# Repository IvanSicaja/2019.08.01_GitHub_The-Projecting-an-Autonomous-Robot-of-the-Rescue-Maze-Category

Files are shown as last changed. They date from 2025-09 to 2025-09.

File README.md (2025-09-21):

🧾 🎯 **Project Title:** **THE PROJECTING AN AUTONOMOUS ROBOT OF THE RESCUE MAZE CATEGORY**  
📅 **Project Timeline:** **August 2019 – October 2021**  
🎥 YouTube Demo: [Link: https://youtu.be/3sTD7d_HzC4](https://youtu.be/3sTD7d_HzC4)  
📦 GitHub Source Code: <https://github.com/IvanSicaja/2019.08.01_GitHub_The-Projecting-an-Autonomous-Robot-of-the-Rescue-Maze-Category>  
\----------------------------------------------------------------------------------------------------------------

🏷️ My Personal Profiles: ⬇︎  
🎥 Video Portfolio: To be added  
📦 GitHub Profile: <https://github.com/IvanSicaja>  
🔗 LinkedIn: <https://www.linkedin.com/in/ivan-si%C4%8Daja-832682222>  
🎥 YouTube: <https://www.youtube.com/@ivan_sicaja>  
\----------------------------------------------------------------------------------------------------------------

### 📚🔍 Project description: ⬇︎⬇︎⬇︎

### 💡 App Purpose

To design a **rescue maze mobile robot** with autonomous **navigation, victim detection, and package delivery**, capable of operating in **unpredictable rescue environments** with robust AI-driven perception.

**Key Robot Capabilities:**

- **Autonomous character recognition (OCR)**
- **Autonomous color recognition**
- **Partially autonomous drive in the maze** (need a lot of testing and calibration for fully autonomous drive and labyrinth mapping)
- **Thermal victim recognition**
- **Package delivery**
- **Ability to master a climb of 25 degrees** (all-wheel drive, strong grip)
- **Independent axle maneuvering**
- **Remembering positions (encoders)**...

**🧠 How It Works**  
The project is very complex and demands knowledge in different areas (**3D modeling, 3D printing, advanced programming skills in different languages, researching ability, expert knowledge of every electrical component working principles, image processing, cause-and-effect analysis...**)  
The brains of the robot are **microcontroller Teensy 3.5** and **Raspberry Pi 4B**.

The robot is also equipped with:

- **2x optical camera**
- **2x thermal camera**
- **6x IR lidar sensor**
- **1x color sensor**... (more can be found at GitHub in my publication paper: _The projecting an autonomous robot of the rescue maze category.pdf_ -> Caption 4.3)

**Optical character recognition:**  
In this project, we trained a **Convolutional Neural Network (CNN)** on an image examples with the Python module **TensorFlow**. Images are converted into **.CSV file** because of speeder processing. The input image is filtered with different filters (**Grayscale, Gaussian Blur, Threshold, Binary, Dilatation**) in order to speed up image processing (replace three color channels with one channel, **RGB -> grayscale**). Reduce noises (the dust on the live video capturing). Getting smooth and sharp character edges is the most important characteristic for successful character recognition. The trained model accuracy is **77.54%** which is a target because we want to get high reliability and avoid CNN overfitting.

**Object detection:**  
Developed the custom script with the Python computer vision module **OpenCV** which filters the character that should be recognized from the other objects in the robot's surroundings. The script works on the principle of **character height and proportion**, together with the **dynamic noise filtering**.

**Maze mapping:**  
Maze mapping is done in my Python module **Turtle**. Every maze field is properly recognized by the robot's **distance and color sensors**. After all maze fields are mapped, they are sent to the backend and the shortest path is calculated by the artificial intelligence searching algorithms such as: _Breadth-First Search, Depth-First Search, A Algorithm_\*...

**Hardware choosing and connecting:**  
The entire process of choosing **hardware platforms, supported protocols, and hardware capabilities** is done. E.g. the **video camera** must have a corresponding **focal length** otherwise it will be useless, **framerate, resolution, additional light source**, **motors** should have expected speed, **distance sensors** should be precise and able to work in a maze, **robot brain** should be able to do high computation payload and support Python…

**Frame design and 3D printing:**  
Entire robot is **3D designed** with **Fusion 360 CAD/CAM** software and **3D printed** with the **Ultimaker 3+** 3D printer with corresponding **filament, density**, etc.

**Developing mechatronic code:**  
**Arduino** is used to control all **sensors and actuators** on the robot except the **camera** which is controlled by **Raspberry Pi 4B** computer.

### ⚠️ Note

Achieving fully **autonomous drive** and **labyrinth mapping** requires extensive testing and calibration.  
I would especially like to thank **Mirko Pezo** and **Stjepan Mikulic** for their exceptional contribution to the development of this project .

### 🔧 Tech Stack

**Python, Convolutional Neural Network (CNN), OpenCV – Computer Vision, Pandas, TensorFlow, Keras, scikit-learn, Git, Linux, Fusion 360, 3D design, 3D printing, Arduino, Raspberry Pi, Teensy, Visual Studio Code, Turtle (Python), AI Search Algorithms (BFS, DFS, A\*)**

---

### 📸 Project Snapshot

<p align="center">
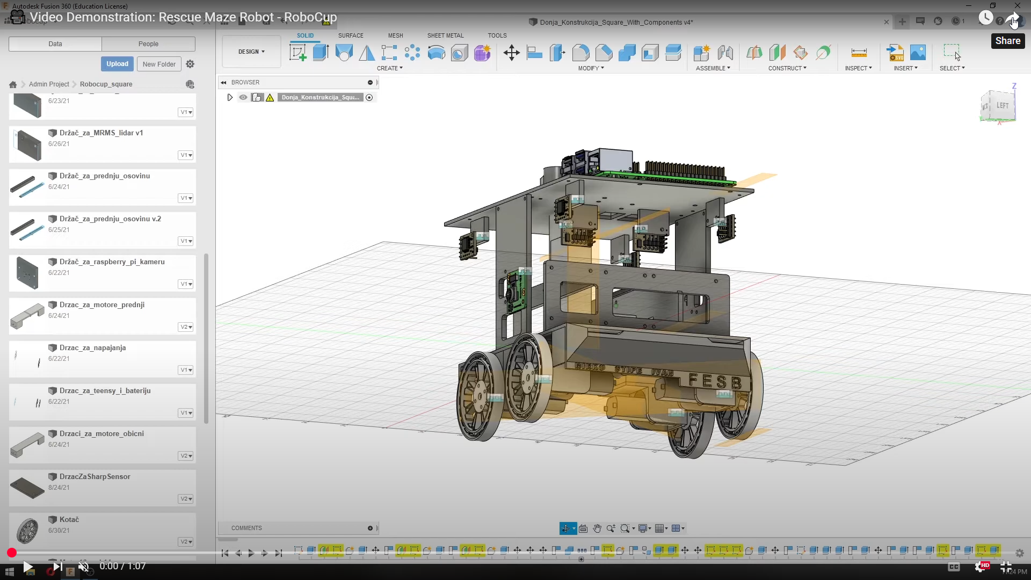
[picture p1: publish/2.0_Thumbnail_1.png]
Rescue Maze Robot Preview 1
  
</p>

<p align="center">
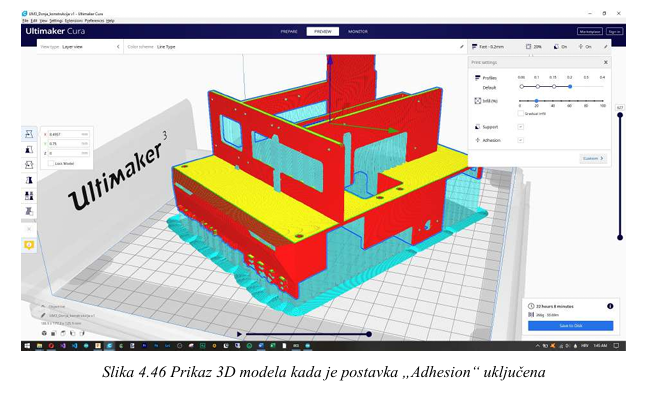
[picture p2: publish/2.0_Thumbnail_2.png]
Rescue Maze Robot Preview 2
  
</p>

<p align="center">
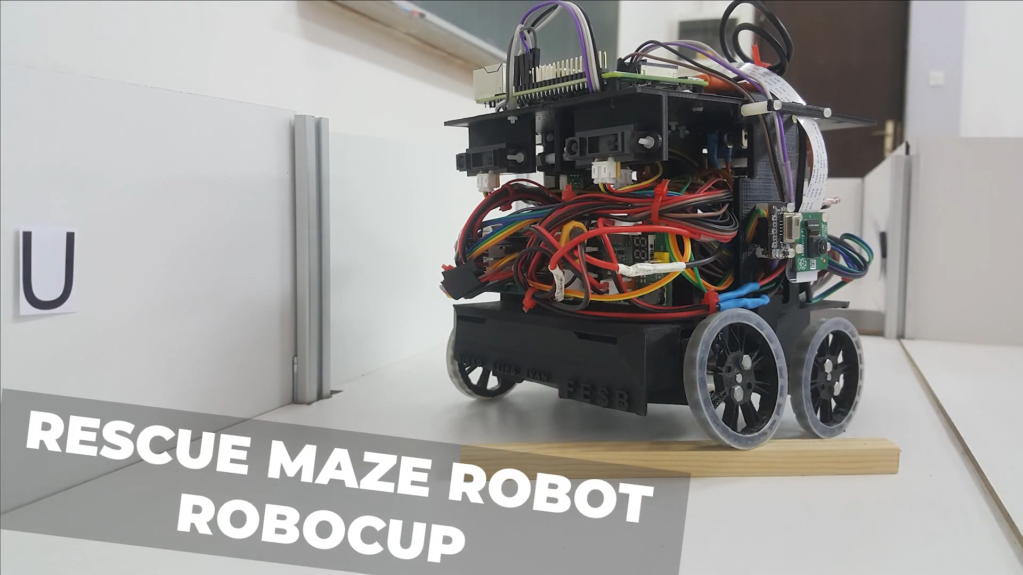
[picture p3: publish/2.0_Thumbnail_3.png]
Rescue Maze Robot Preview 3
  
</p>

<p align="center">
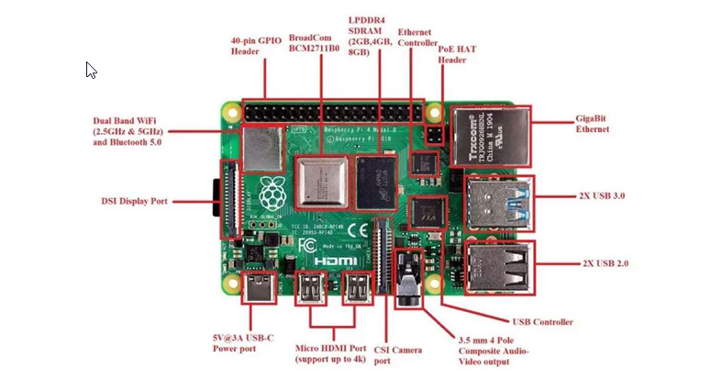
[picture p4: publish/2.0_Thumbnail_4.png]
Rescue Maze Robot Preview 4
  
</p>

<p align="center">
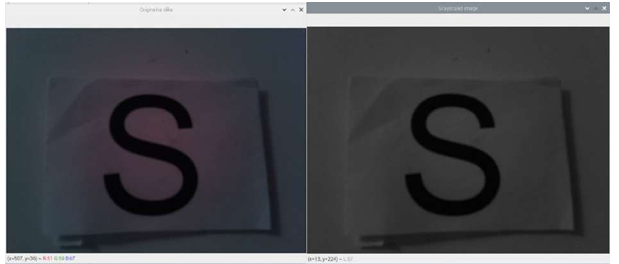
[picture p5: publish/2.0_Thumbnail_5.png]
Rescue Maze Robot Preview 5
  
</p>

<p align="center">
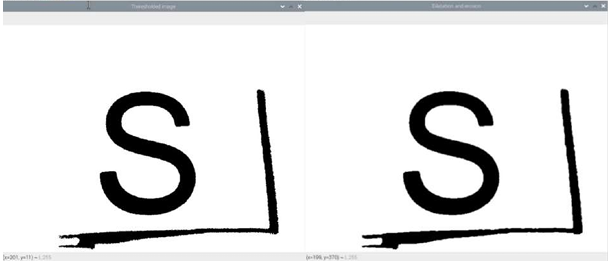
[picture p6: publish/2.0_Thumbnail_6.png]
Rescue Maze Robot Preview 6
  
</p>

<p align="center">
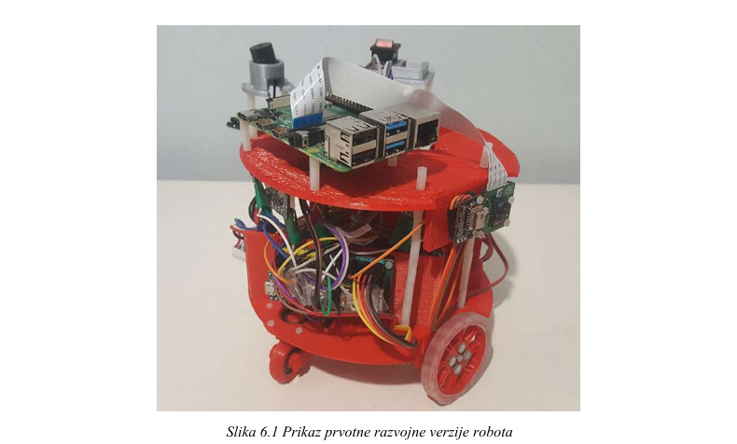
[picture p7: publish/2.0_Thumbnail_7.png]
Rescue Maze Robot Preview 7
  
</p>

---

### 🎥 Video Demonstration

<p align="center">
  <a href="https://youtu.be/3sTD7d_HzC4">
    Watch the demo
  </a>
</p>

---

### 📣 Hashtags Section

**\# #AutonomousRobotics #RescueMaze #RoboticsEngineering #AI #ComputerVision #OCR #ObjectDetection #PathPlanning #CNN #TensorFlow #OpenCV #EmbeddedSystems #RaspberryPi #Arduino #3DPrinting #Fusion360 #Mechatronics #AutonomousNavigation #MachineLearning**

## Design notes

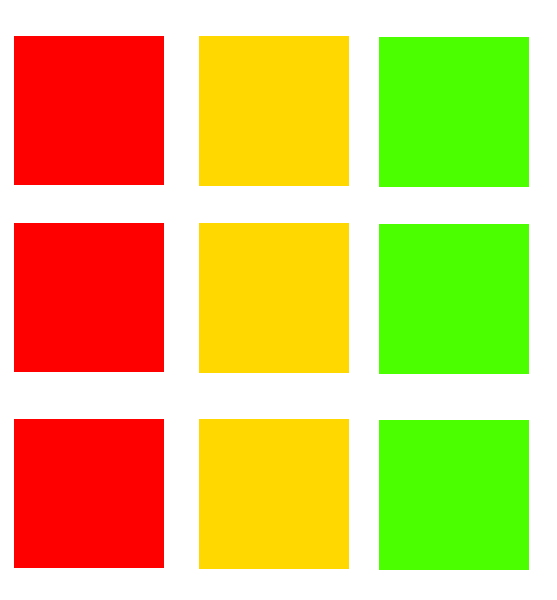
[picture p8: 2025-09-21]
docs/labyrinth/colorTarget.png

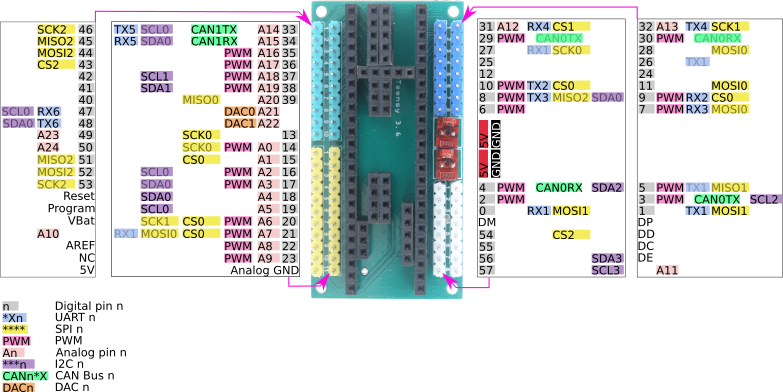
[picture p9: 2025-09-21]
docs/teensy/Teensy_3.6_Adapter_Pins.png

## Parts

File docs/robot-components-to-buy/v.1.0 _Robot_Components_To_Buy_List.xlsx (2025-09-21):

Number | Item | Quantity which we have | Item Price [$] | Price | Item Weight [g] | Weight [g] | Link
1 | Mikrokontrloer | 1 |  |  |  |  | https://www.pjrc.com/store/teensy36.html
2 | DC motors | 2 |  |  |  |  | https://www.pololu.com/product/3492
3 | DC motors Connectors | 2 |  |  |  |  | https://www.microline.hr/HTML.ashx?id=101
4 | Board for Tennesy | 1 |  |  |  |  | https://www.microline.hr/HTML.ashx?id=83
5 | Transformator and 8x8 display | 1 |  |  |  |  | https://www.microline.hr/HTML.ashx?id=40
6 | Motor Driver | 1 |  |  |  |  | https://www.microline.hr/HTML.ashx?id=37
7 | Themo Sensor | 1 |  |  |  |  | https://www.microline.hr/HTML.ashx?id=178
8 | Compas | 1 |  |  |  |  | https://www.microline.hr/HTML.ashx?id=140
9 | Position sensor | 1 |  |  |  |  | https://www.microline.hr/HTML.ashx?id=148
10 | PDB | 1
11 | Micro SD card
12 | Camrea | 1
13 | Raspberry PI 4 | 1 |  |  |  |  | https://www.raspberrypi.org/blog/raspberry-pi-4-on-sale-now-from-35/
14 | Raspberry PI 4 Camera V2 | 1 |  |  |  |  | https://www.raspberrypi.org/products/camera-module-v2/
15 | Line-traking sensor
16 | Battery | 1 |  |  |  |  | https://www.amazon.co.uk/Lipo-Battery-Turnigy-Nano-Tech-1300-mAh/dp/B018S936C8
17 | Frame
18 | Ampermeter
19 | Shaft Adpters | 4 |  |  |  |  | https://www.pololu.com/product/1081
Total

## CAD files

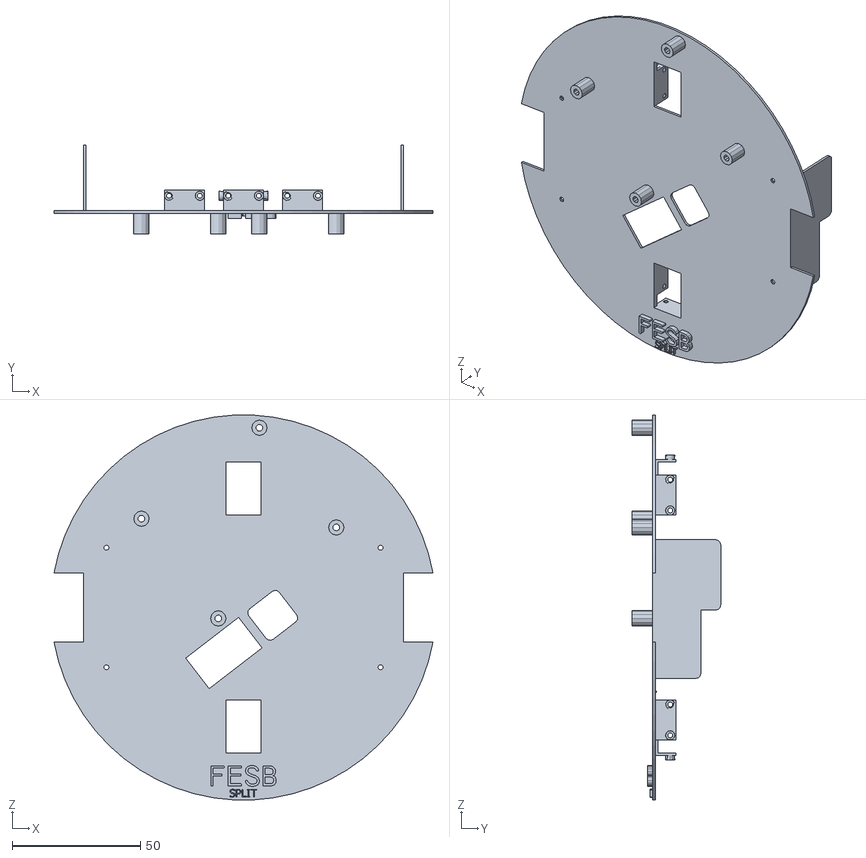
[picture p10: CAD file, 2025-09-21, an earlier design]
assets/3d-modeling/3D_Robot_Body_Parts_v.2.0/STL_files_for_print/Gornja_konstrukcija_s_držačima_assembly_converted_v.3.0.stl
147.5 x 34.5 x 149.8

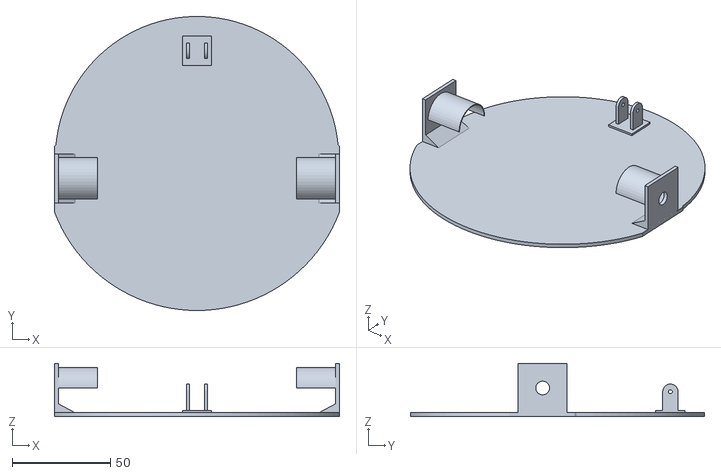
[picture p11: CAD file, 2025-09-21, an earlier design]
assets/3d-modeling/3D_Robot_Body_Parts_v.1.0/Konstrukcija/v.1.1 Konstrukcija.stl
145.0 x 149.5 x 27.0

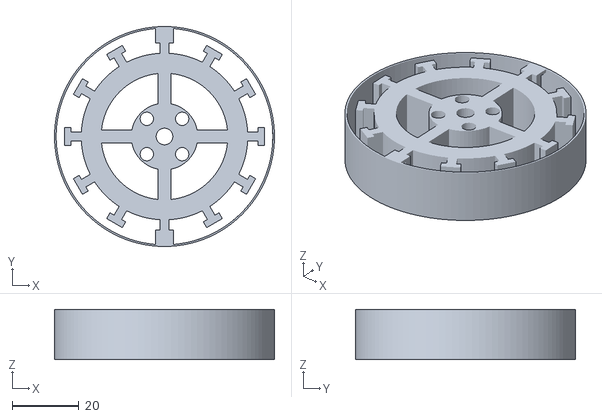
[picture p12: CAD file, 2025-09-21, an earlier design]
assets/3d-modeling/3D_Robot_Body_Parts_v.1.0/Kotači/3.0 kotač.stl
66.0 x 66.0 x 15.0

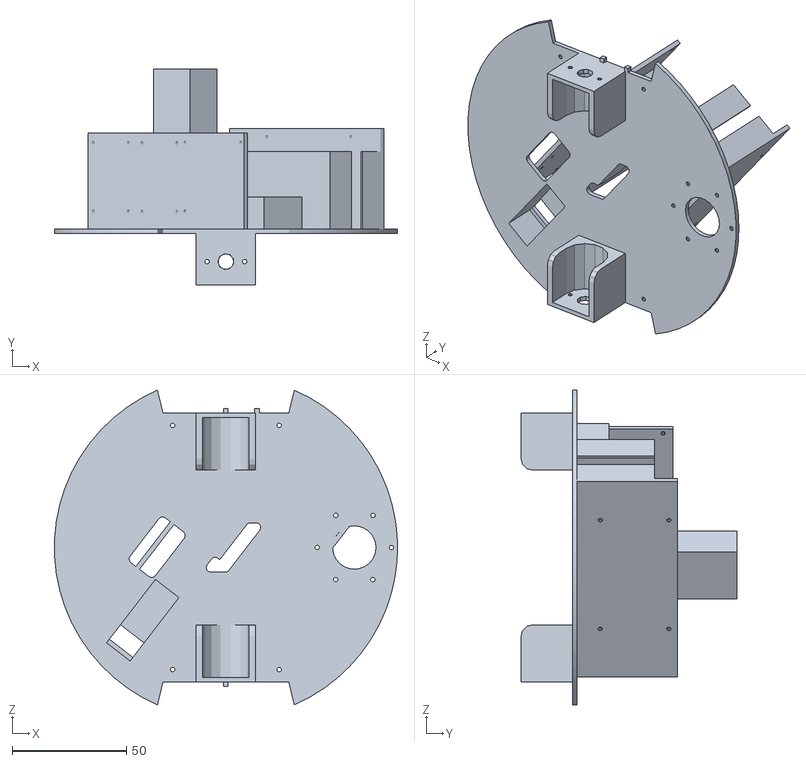
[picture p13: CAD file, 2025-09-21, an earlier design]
assets/3d-modeling/3D_Robot_Body_Parts_v.2.0/1_NewScratches/STL_Files/DonjaKonstrukcija_v.5.0..stl
149.9 x 94.4 x 137.6

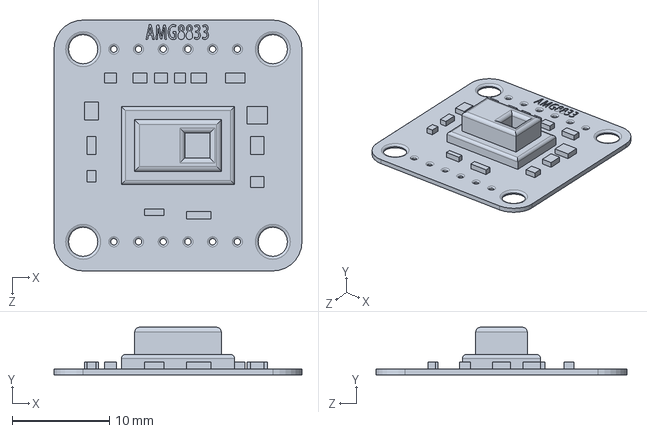
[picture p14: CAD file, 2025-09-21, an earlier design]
assets/3d-modeling/3D_Robot_Body_Parts_v.2.0/AdfruitThermalSensor/Camara AMG8833.SLDPRT
25.5 x 4.90 x 25.8 mm

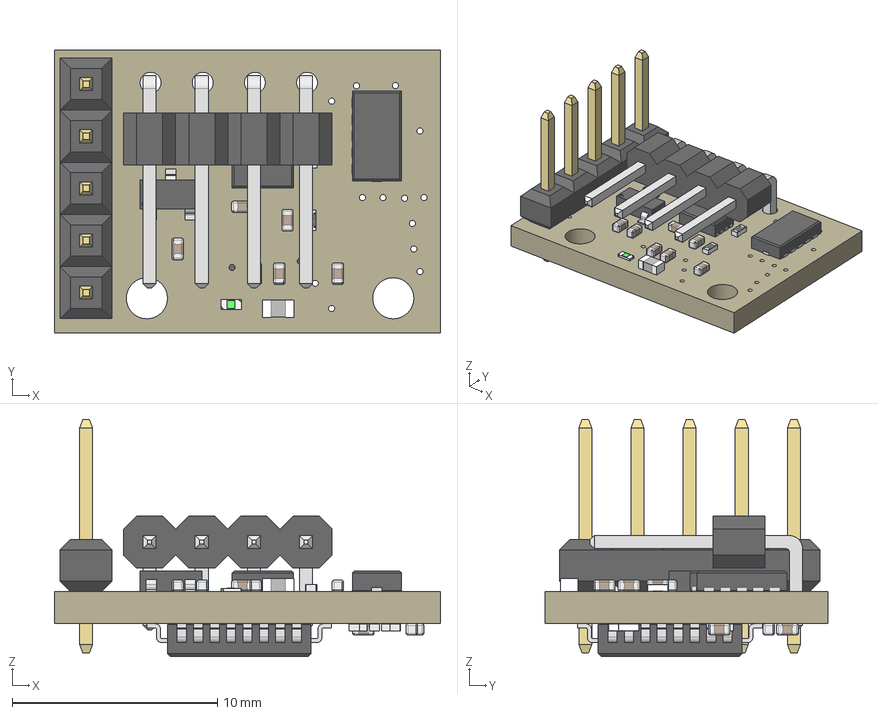
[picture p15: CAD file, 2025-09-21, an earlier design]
assets/3d-modeling/3D_Robot_Body_Parts_v.2.0/Lidar_MRMS/mrm-lid-an.step
18.8 x 13.8 x 11.6 mm
Board
4.7uF x 11
10 kOhm x 7
MICROCHIP_MCP1725T-ADJE/MC
STM_VL53LX
1X05
STM32F051K6T6
1X04_90DEG
SOT-23
FIDUCIAL1X2 x 2
CHIPLED_0402
1.5 kOhm

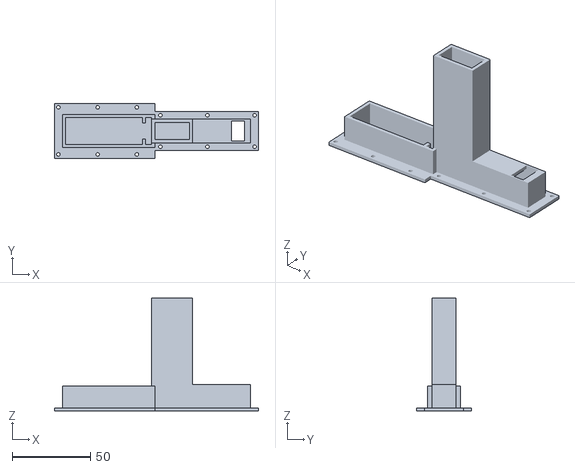
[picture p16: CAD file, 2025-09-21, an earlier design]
assets/3d-modeling/3D_Robot_Body_Parts_v.2.0/OldVersions/DropMechanism_v.1.1.stl
130.0 x 35.0 x 72.0

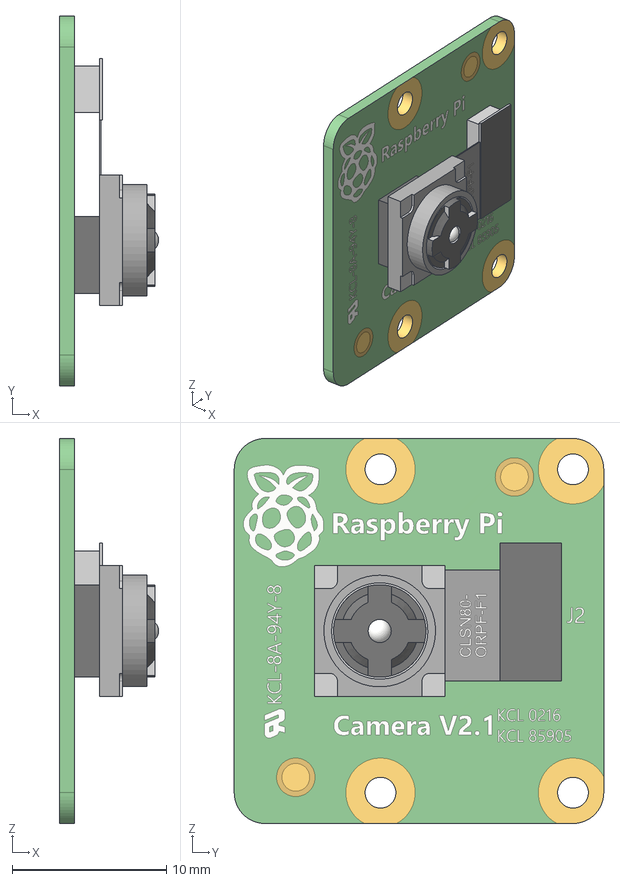
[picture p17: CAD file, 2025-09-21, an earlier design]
assets/3d-modeling/3D_Robot_Body_Parts_v.2.0/Raspberry Pi Camera Module 2.1/Cam V2.1 v1.step
6.45 x 24.0 x 25.0 mm

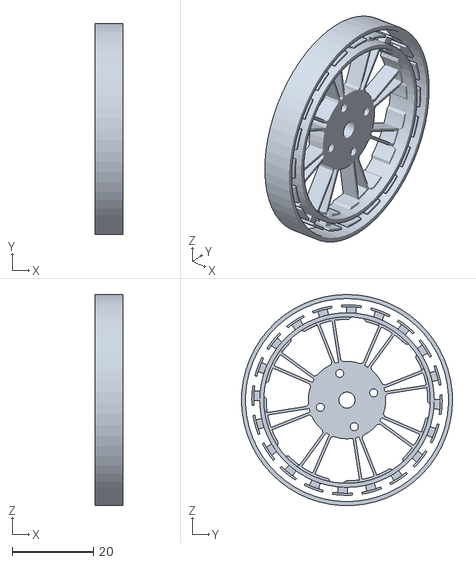
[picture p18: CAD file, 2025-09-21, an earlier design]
assets/3d-modeling/3D_Robot_Body_Parts_v.2.0/STL_files_for_print/Kotač_v.3.0..stl
7.00 x 52.0 x 52.0

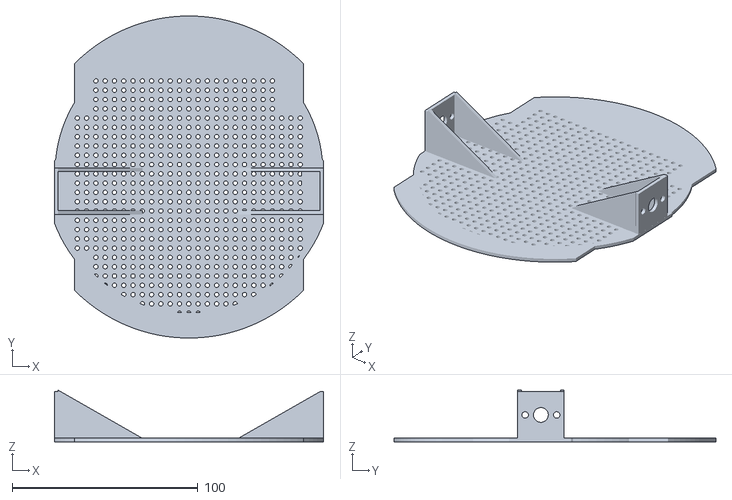
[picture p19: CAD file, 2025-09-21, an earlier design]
assets/3d-modeling/3D_Robot_Body_Parts_v.1.0/Konstrukcija/2.0 konstrukcija .stl
145.0 x 173.3 x 27.9

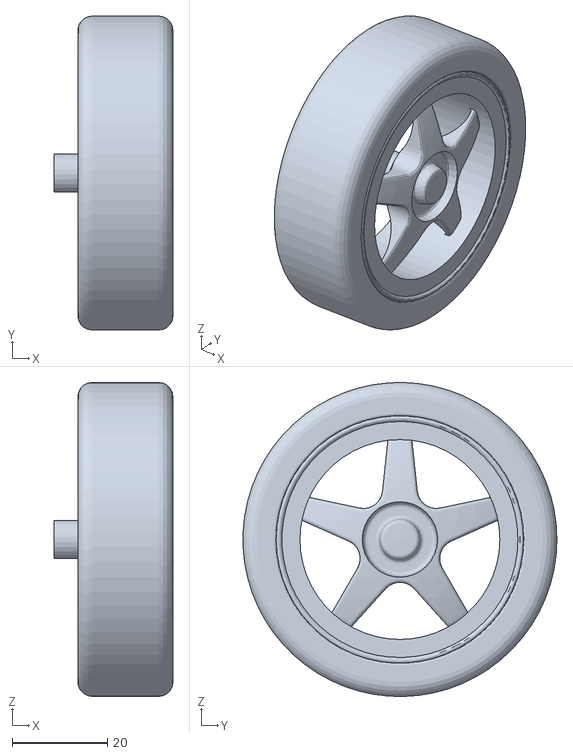
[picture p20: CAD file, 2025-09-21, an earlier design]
assets/3d-modeling/3D_Robot_Body_Parts_v.1.0/Kotači/v1.0 Kotač.obj
25.0 x 66.0 x 66.0

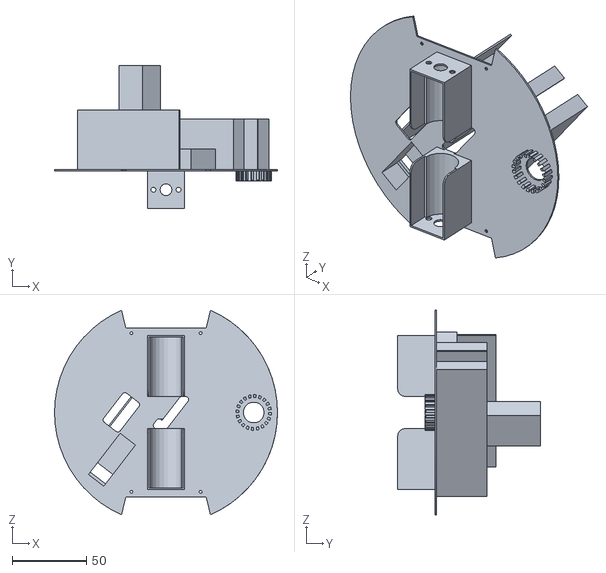
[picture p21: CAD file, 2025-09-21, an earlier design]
assets/3d-modeling/3D_Robot_Body_Parts_v.2.0/STL_files_for_print/Donja_konstrinkcija_s_drop_mehanizmom_v.2.stl
150.0 x 96.0 x 137.6

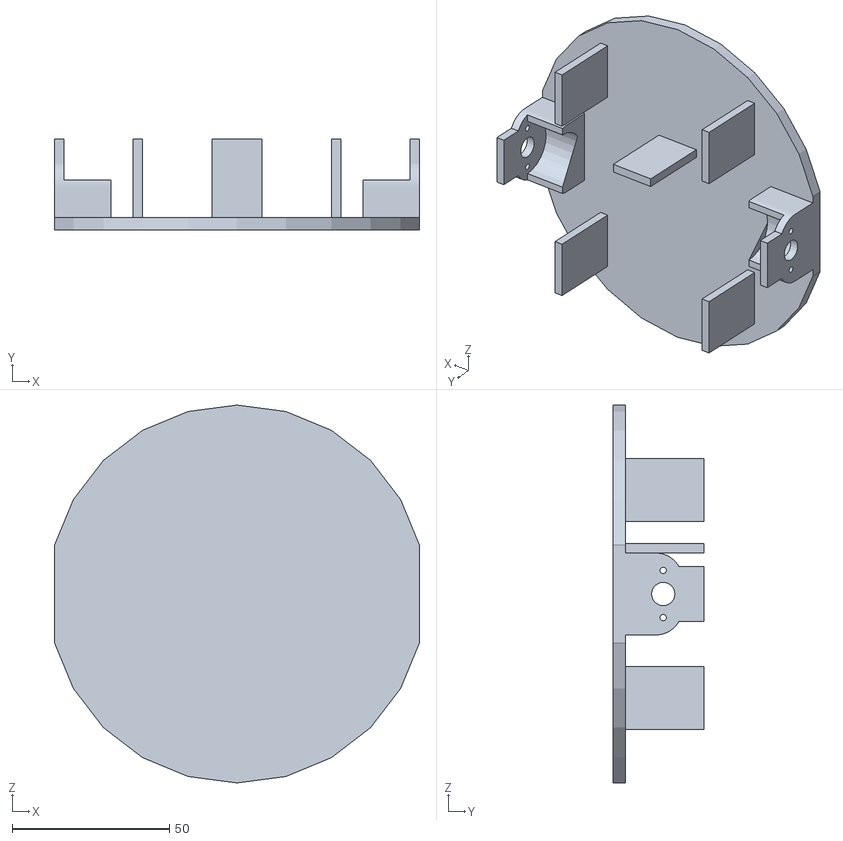
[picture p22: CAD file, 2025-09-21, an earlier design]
assets/3d-modeling/3D_Robot_Body_Parts_v.1.0/Konstrukcija/v.1.0 Konstrukcija.obj
115.9 x 29.0 x 120.0

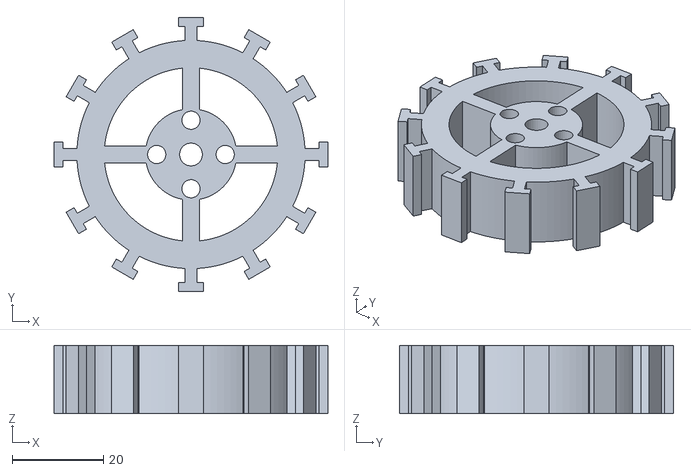
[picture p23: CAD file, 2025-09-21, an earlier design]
assets/3d-modeling/3D_Robot_Body_Parts_v.1.0/Kotači/v2.0 Kotač.stl
60.0 x 60.0 x 15.0

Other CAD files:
assets/3d-modeling/3D_Robot_Body_Parts_v.1.0/Konstrukcija/v.1.2 Konstrukcija.stl
assets/3d-modeling/3D_Robot_Body_Parts_v.1.0/Kotači/2.0 kotač s pomoći za ispunu s ljepilom.stl
assets/3d-modeling/3D_Robot_Body_Parts_v.2.0/STL_files_for_print/Paketici_za_izbacivanje_v.1.0.stl
assets/3d-modeling/3D_Robot_Body_Parts_v.2.0/STL_files_for_print/PrednjiKotač_635z_lezaj_v.2.0.stl
assets/3d-modeling/3D_Robot_Body_Parts_v.2.0/1_NewScratches/DodatniDržačZaLežaj_v.3.0.ipt
assets/3d-modeling/3D_Robot_Body_Parts_v.2.0/1_NewScratches/DonjaKonstrukcija_v.5.0.iam
assets/3d-modeling/3D_Robot_Body_Parts_v.2.0/1_NewScratches/DonjaKonstrukcija_v.5.0.ipt
assets/3d-modeling/3D_Robot_Body_Parts_v.2.0/1_NewScratches/DropMechanism_v.2.0.ipt
assets/3d-modeling/3D_Robot_Body_Parts_v.2.0/1_NewScratches/DrzacZaMotor_v.3.0.ipt
assets/3d-modeling/3D_Robot_Body_Parts_v.2.0/1_NewScratches/DrzacZaPrednjiKotač_v.1.0.ipt
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

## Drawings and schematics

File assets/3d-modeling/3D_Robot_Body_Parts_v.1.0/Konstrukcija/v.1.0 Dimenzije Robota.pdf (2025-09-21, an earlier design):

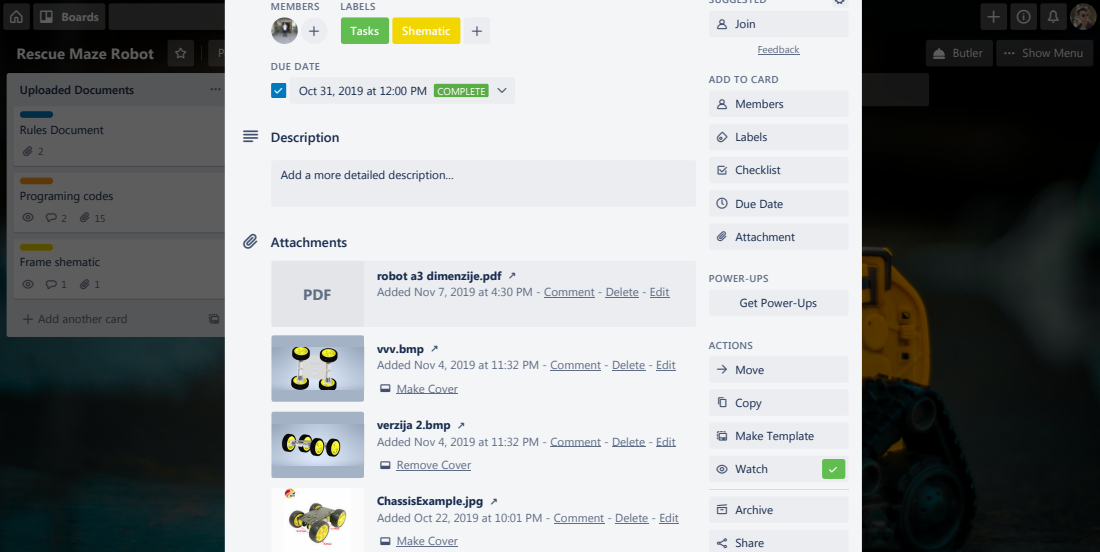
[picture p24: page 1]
Rescue Maze Robot; Personal; Private; Invite; Butler; Show Menu; Uploaded Documents; Current Tasks; Done Tasks; Rules Document; Programing codes; Frame shematic; Boards; MEMBERS; LABELS; DUE DATE; Tasks; Shematic; SUGGESTED; Feedback; Join; Labels; Checklist; Due Date; Attachment; ACTIONS; Move; Copy; Make Template; Watch; Archive; Share

ADD TO CARD
Add another list
Members

Oct 31, 2019 at 12:00 PM COMPLETE

Stuff that we need
Description
Add a more detailed description…
The Labyrinth Mapping Solutions
Jan 15
Attachments
Add another card
PDF

Kontrola motora (-10 - 10) "-10 ful
brzina naprijed, 10 ful brzina nazad"

robot a3 dimenzije.pdf
Added Nov 7, 2019 at 4:30 PM - Comment - Delete - Edit

POWER-UPS
Get Power-Ups

Make a simple frame construction
shematic for 4 motors
Oct 31, 2019 2 4

vvv.bmp
Added Nov 4, 2019 at 11:32 PM - Comment - Delete - Edit
Make Cover

verzija 2.bmp
Remove Cover

ChassisExample.jpg
Added Oct 22, 2019 at 10:01 PM - Comment - Delete - Edit

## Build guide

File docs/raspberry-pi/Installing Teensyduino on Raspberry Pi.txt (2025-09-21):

### Install Teensy ###

Must be directly (HDMI) connected to Raspberry

git clone https://github.com/cmcmurrough/cse2100
cd cse2100
cd teensy/
sudo sh install_teensyduino.sh

### Second Way Official Website###
Dowload Udev rules than run
sudo cp 00-teensy.rules /etc/udev/rules.d/
After Arduino Linux 32 installation run
./TeensyduinoInstall.linux64
If instalation error do next
sudo cp /tmp/49-teensy.rules /etc/udev/rules.d

### Uninstall app ###
sudo apt-get remove arduino-core 

sudo apt-get install arduino

### Install Arduino ###

Download from site Linux ARM 32 bit

tar xf ~/Downloads/arduino-1.6.11-linux32.tar.xz -C ~/
cd arduino1.6.11/
sudo ./install.sh
or just ./install.sh
### Enable Teensy Serial Communication ###

Download Linux Udev File from PRJC Teensyduino file
Than run: sudo cp 00-teensy.rules /etc/udev/rules.d/

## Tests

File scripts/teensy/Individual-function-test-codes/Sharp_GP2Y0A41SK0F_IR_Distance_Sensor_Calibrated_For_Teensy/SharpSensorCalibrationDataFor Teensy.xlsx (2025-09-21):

Udaljenost [cm] | Izlazni napon Sharp IR Senzora [V] | Udaljenost [cm] | Izlazni napon Sharp IR Senzora [V]
1 | 2.41 | 4 | 3.8
2 | 3.42 | 5 | 3.17
3 | 4.4 | 6 | 2.73
4 | 3.8 | 7 | 2.41
5 | 3.17 | 8 | 2.13
6 | 2.73 | 9 | 1.9
7 | 2.41 | 10 | 1.73
8 | 2.13 | 11 | 1.57
9 | 1.9 | 12 | 1.46
10 | 1.73 | 13 | 1.34
11 | 1.57 | 14 | 1.25
12 | 1.46 | 15 | 1.19
13 | 1.34 | 16 | 1.1
14 | 1.25 | 17 | 1.04
15 | 1.19 | 18 | 0.99
16 | 1.14 | 19 | 0.95
17 | 1.04 | 20 | 0.9
18 | 0.99 | 21 | 0.85
19 | 0.95 | 22 | 0.82
20 | 0.9 | 23 | 0.78
21 | 0.85 | 24 | 0.75
22 | 0.82 | 25 | 0.71
23 | 0.78 | 26 | 0.68
24 | 0.75 | 27 | 0.65
25 | 0.71 | 28 | 0.63
26 | 0.68 | 29 | 0.61
27 | 0.65 | 30 | 0.6
28 | 0.63
29 | 0.61
30 | 0.6
31 | 0.57

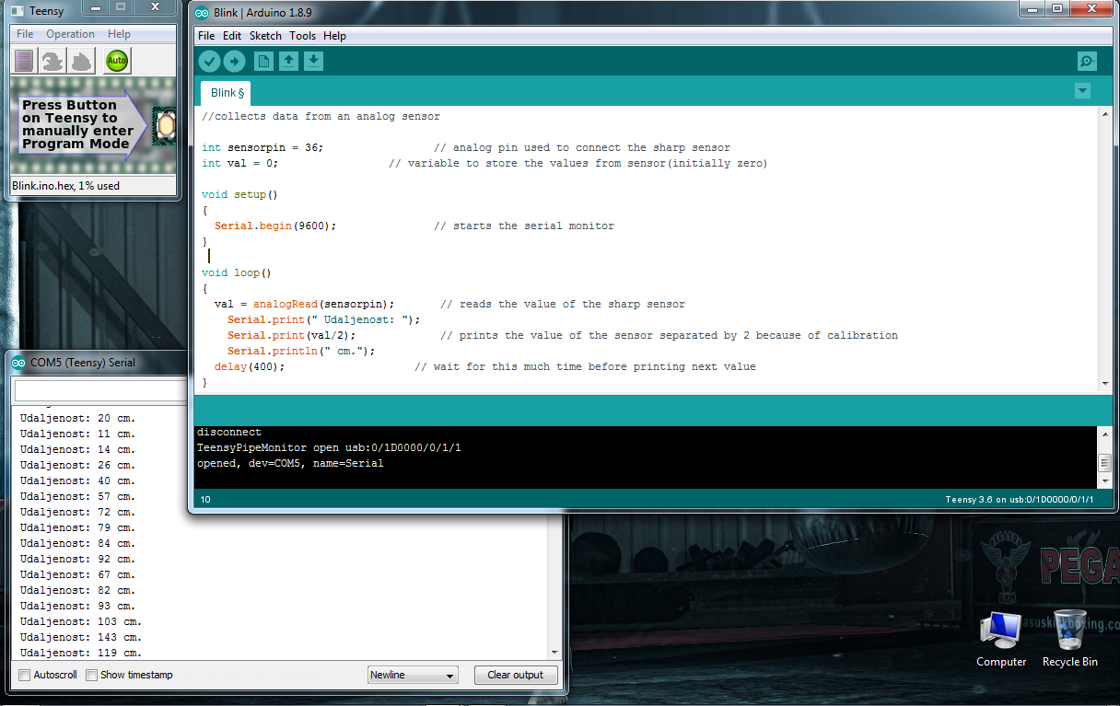
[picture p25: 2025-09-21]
scripts/teensy/Individual-function-test-codes/Senzor udaljenosti (MRMS LIDAR 2m VL53L0X)/v.1.0_Distance_sensor.png

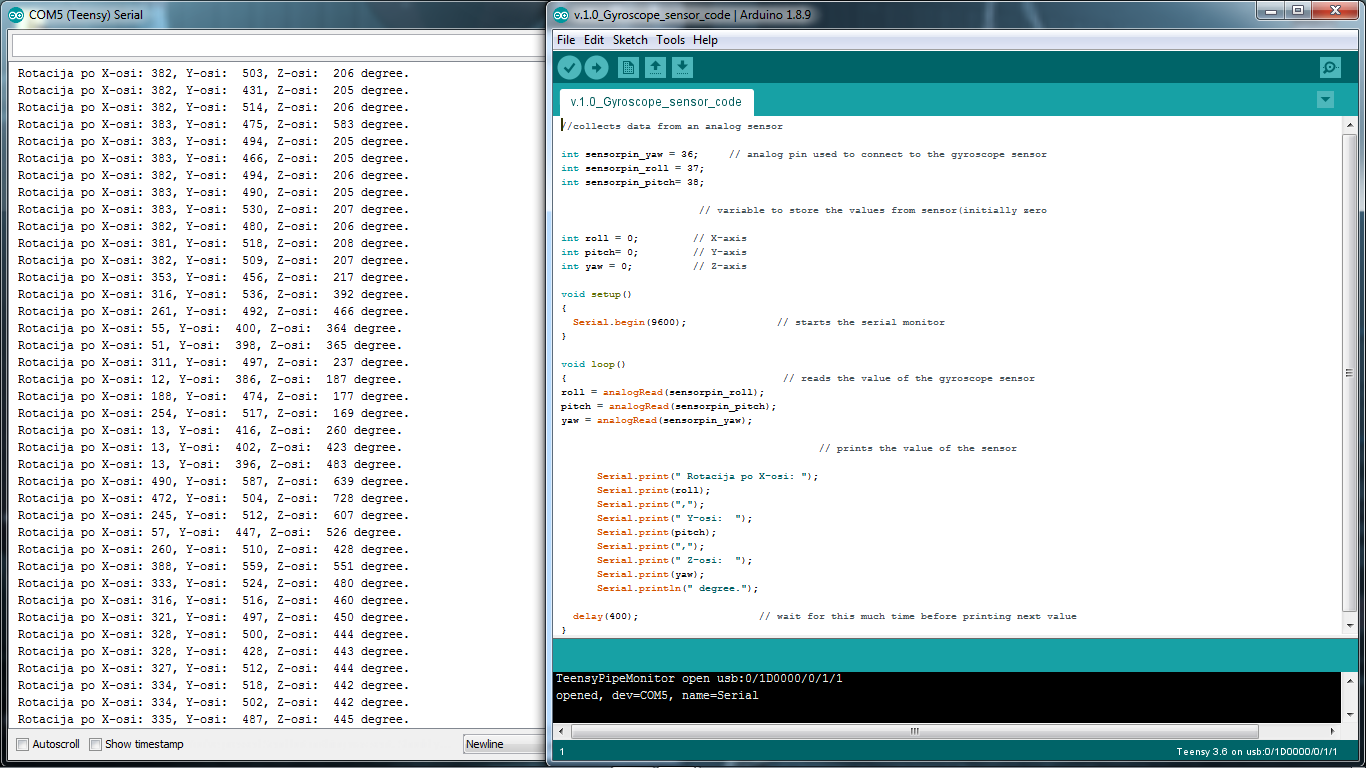
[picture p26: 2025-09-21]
scripts/teensy/Individual-function-test-codes/Gyroscope/v.1.0_Gyroscope_sensor.png

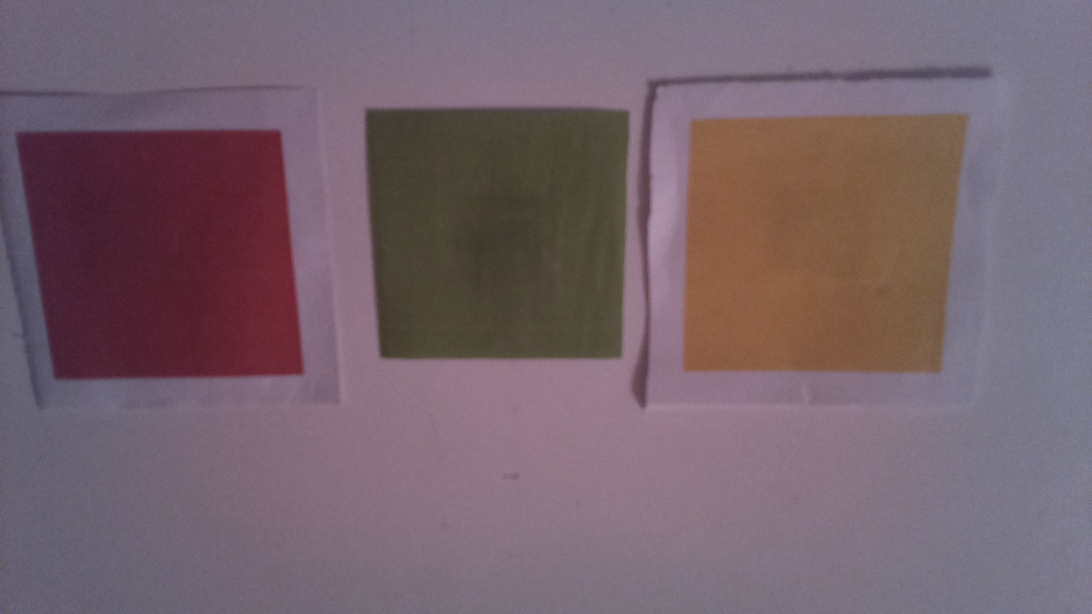
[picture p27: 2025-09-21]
main/raspberry-pi/computer-vision/v.4.3_image-recognition_respberry-pi_fully-robot-integrated/1.Step/color-victims-images-for-camera-calibration/Yellow_victim.png

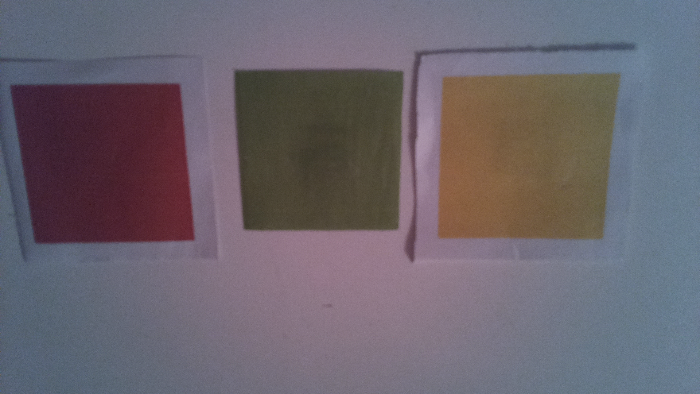
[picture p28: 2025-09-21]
scripts/raspberry-pi/computer-vision/v.4.3_ImageRecognition/1.Step/Color_victims_images_for_calibration/Red_victim.png

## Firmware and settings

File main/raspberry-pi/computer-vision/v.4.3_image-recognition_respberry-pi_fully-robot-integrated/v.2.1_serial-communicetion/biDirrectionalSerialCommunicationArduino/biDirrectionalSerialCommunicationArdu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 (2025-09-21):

unsigned long startMillis;  //some global variables available anywhere in the program
unsigned long currentMillis;
void setup() {
  pinMode(LED_BUILTIN, OUTPUT);

  Serial.begin(9600);
  startMillis = millis();

}

void loop() {

  //Slanje texta na Serijski port Raspberry-a

  currentMillis = millis();
  //Serial.println(startMillis );
  //Serial.println(currentMillis);


  if ((currentMillis - startMillis) > 3000)
  {
    Serial.println("TFND");
    startMillis = currentMillis;
  }

  //delay(200);


  //Ocitanje texa koji dolazi na Arduino serijski port
  
  if (Serial.available() > 0) {

    String data = Serial.readStringUntil('\n');

    if (data.substring(0) == "HFND") {
      Serial.println("FOUND");

    }
    if (data.substring(0) == "SFND") {
      Serial.println("FOUND");

    }
    if (data.substring(0) == "UFND") {
      Serial.println("FOUND");

    }
    if (data.substring(0) == "TFND") {
      Serial.println("FOUND");

    }

    //Serial.print("You sent me: ");

    //  Serial.println(data);

  }

}

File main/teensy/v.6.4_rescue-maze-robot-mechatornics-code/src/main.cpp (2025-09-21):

// Regulators calibrated
// Added condition to giroscope while loop
// Added forward distance sensors value for else if conditions on main loop
// Added else condition
// Added or logic for condition of p-regulators loop
// Added Keep optimal distances to autonomus function
// Added time interval to giroscope and keep optimal distances regulators
// Adding boolean condition for turn-on and turn-off refulators of main loop
// Adding Digital and Analog Read/Write Fast

// added temperature sensor -> needs calibration
// added encoder with interrupts
// 1525 encoder readings is 360 degrees whell rotation actually 157.1 mm
// 50 mm makes with 485 impulses
// Maximal motor speed is 100
// Z orientation Tolerance = 13
// 17 is minimum speed of one wheel if one wheel speed is higer of 19


#include "Robot_Gibanje.h"

ROBOT_GIBANJE robot;

void setup()
{


  Serial.begin(115200); // Start communication with a computer connected to Teensy via a USB cable
  Serial.println("I am in setup loop.");
  robot.Setup_For_All_Components();   

  delay(1000);
}

void loop()
{

  //####################################################################################################
  
  bool ArduinoStartsCommunication = false;

  while (ArduinoStartsCommunication != true)
  {
    if (Serial.available() > 0)
    {

      String data = Serial.readStringUntil('\n');

      if (data.substring(0) == "START!")
      {
        ArduinoStartsCommunication = true;
        Serial.println("START!");
      }
    }
  }

robot.Go_Autonomus_Adventage_Version_Optimized();






  }

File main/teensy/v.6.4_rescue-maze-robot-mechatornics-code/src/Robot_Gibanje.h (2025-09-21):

#ifndef Robot_Gibanje_h
#define Robot_Gibanje_h

//############################################################## Includeing libraries ##############################################################

#include <Arduino.h>

#include <Wire.h>             //
#include <Adafruit_Sensor.h>  //
#include <Adafruit_BNO055.h>  // Library used for read gyroscope data from Adafruit BNO055 
#include <util/atomic.h>      // Library used for createing atomic blocks which is used with read encoders functions
#include <utility/imumaths.h> //

//################################################################ Pins definitions ################################################################

#define SPEED_BACK_LEFT_MOTOR_PIN 2       // 1. motor - pin for motor speed
#define DIRECTION_BACK_LEFT_MOTOR_PIN 3   // 1. motor - pin for motor direction
#define SPEED_BACK_RIGHT_MOTOR_PIN 4      // 2. motor - pin for motor speed
#define DIRECTION_BACK_RIGHT_MOTOR_PIN 5  // 2. motor - pin for motor direction
#define SPEED_FRONT_LEFT_MOTOR_PIN 6      // 3. motor - pin for motor speed
#define DIRECTION_FRONT_LEFT_MOTOR_PIN 7  // 3. motor - pin for motor direction
#define SPEED_FRONT_RIGHT_MOTOR_PIN 8     // 4. motor - pin for motor speed
#define DIRECTION_FRONT_RIGHT_MOTOR_PIN 9 // 4. motor - pin for motor direction

#define ENCODER_LEFT_A_OUT 54  // Left encoder - A output pin
#define ENCODER_LEFT_B_OUT 55  // Left encoder - B output pin
#define ENCODER_RIGHT_A_OUT 56 // Right encoder - A output pin
#define ENCODER_RIGHT_B_OUT 57 // Right encoder - B output pin

#define ELECTROMAGNET_PIN1 29 // Not used - solednoid is controlled by Raspberry Pi
#define ELECTROMAGNET_PIN2 30 // Not used - solednoid is controlled by Raspberry Pi

#define FORWARD1_AN_PIN 33 // Forward Left LIDAR - analog output pin
#define FORWARD2_AN_PIN 34 // Forward Right LIDAR - analog output pin
#define LEFT1_AN_PIN 35    // Left Front LIDAR - analog output pin
#define LEFT2_AN_PIN 36    // Left Back LIDAR - analog output pin
#define RIGHT1_AN_PIN 37   // Right Front LIDAR - analog output pin
#define RIGHT2_AN_PIN 38   // Right Back LIDAR - analog output pin

#define LEFT_THERMAL_CAM_OUT_PIN 23  // Left thermal camera - analog output pin
#define RIGHT_THERMAL_CAM_OUT_PIN 22 // Right thermal camera - analog output pin

#define S0 46        // Color sensor - pin used for color snesor output fequency scalling
#define S1 45        // Color sensor - pin used for color snesor output fequency scalling
#define S2 44        // Color sensor - pin used for choose reading color from color sensor
#define S3 43        // Color sensor - pin used for choose reading color from color sensor
#define sensorOut 42 // Color sensor - output

//###################################################### Class and class functions definitions ##########################################################

class ROBOT_GIBANJE
{

    //##################################################### Define class constructor and destructor #####################################################

public:
    ROBOT_GIBANJE();  // Class construktor
    ~ROBOT_GIBANJE(); // Class destructor

    //############################################################## Read sensor functions ##############################################################

    // Read distance sensors functions
    uint16_t Read_Forward_Left_Distance();
    uint16_t Read_Forward_Right_Distance();
    uint16_t Read_Left_Front_Distance();
    uint16_t Read_Left_Back_Distance();
    uint16_t Read_Right_Front_Distance();
    uint16_t Read_Right_Back_Distance();
    void Read_All_Distances(int delayInMicroseconds = 1000); //Successed test
    uint16_t Read_Forward_Left_Distance_Millimetters();
    uint16_t Read_Forward_Right_Distance_Millimetters();
    uint16_t Read_Left_Front_Distance_Millimetters();
    uint16_t Read_Left_Back_Distance_Millimetters();
    uint16_t Read_Right_Front_Distance_Millimetters();
    uint16_t Read_Right_Back_Distance_Millimetters();
    void Read_All_Distances_Millimetters(int delayInMicroseconds = 1000); //Successed test
    //Read gyroscope functions
    float Read_Gyroscope_X_Axis_Orientation(); // Read x-axis robot orientation
    float Read_Gyroscope_Z_Axis_Orientation(); // Read z-axis robot orientation
    //Read thermal camera functions
    void Read_Temperature_Left_Sensor();  // Read left thermal camera value
    void Read_Temperature_Right_Sensor(); // Not defined
    //Read encoder functions
    int Read_Right_Encoder(int right_motor_speed = 20);
    int Read_Left_Encoder(int left_motor_speed = 20);
    // Read color sensor functions
    int getRedPW();
    int getGreenPW();
    int getBluePW();
    int Search_for_Black_or_Grey_tiles(); // Search function for black and grey tiles

    //########################################################## All components setup function ##########################################################

    void Setup_For_All_Components();

    //########################################################## Basic robot moveing functions ##########################################################

    void SetMotorSpeedAndDirection(uint8_t SPEED_PIN, uint8_t DIRECTION_PIN, int motor_speed);
    void Go_Forward(int left_motor_speed = 20, int right_motor_speed = 20);
    void Go_Forward_30cm(int motor_speed = 30); // Not used, undefined - will use encoders to measure 30 cm distance
    void Go_Back(int motor_speed = -30);
    void Go_Back_30cm(int motor_speed = -30); // Not used, undefined - will use encoders to measure 30 cm distance
    void Go_Left(int motor_speed = 30);
    void Go_Right(int motor_speed = 30);
    void Stop_Robot();
    void Rotate_Right_With_Specific_Angle(int angle, int delayTime = 0, int motor_speed = 30); // Angle must be values between 0 and 89 degrees
    void Rotate_Left_With_Specific_Angle(int angle, int delayTime = 0, int motor_speed = 30);  // Angle must be values between 0 and 89 degrees
    void Rotate_Robot_For_180_degrees(int motor_speed = 30);                                   // Rotate robot for 180 degrees

    //############################################################# Wall detection functions ########################################################################

    bool Stopped_Is_Wall_Left_OR_Logic();     //OR logic operator used
    bool Stopped_Is_Wall_Right_OR_Logic();    //OR logic operator used
    bool Stopped_Is_Wall_Forward_OR_Logic();  //OR logic operator used
    bool Stopped_Is_Wall_Left_AND_Logic();    //AND logic operator used
    bool Stopped_Is_Wall_Right_AND_Logic();   //AND logic operator used
    bool Stopped_Is_Wall_Forward_AND_Logic(); //AND logic operator used

    bool Moveing_Is_Wall_Forward_OR_Logic();  //OR logic operator used
    bool Moveing_Is_Wall_Forward_AND_Logic(); //AND logic operator used
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

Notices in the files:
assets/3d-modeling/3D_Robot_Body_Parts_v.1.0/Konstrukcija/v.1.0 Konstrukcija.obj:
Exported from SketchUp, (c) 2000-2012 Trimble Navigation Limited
